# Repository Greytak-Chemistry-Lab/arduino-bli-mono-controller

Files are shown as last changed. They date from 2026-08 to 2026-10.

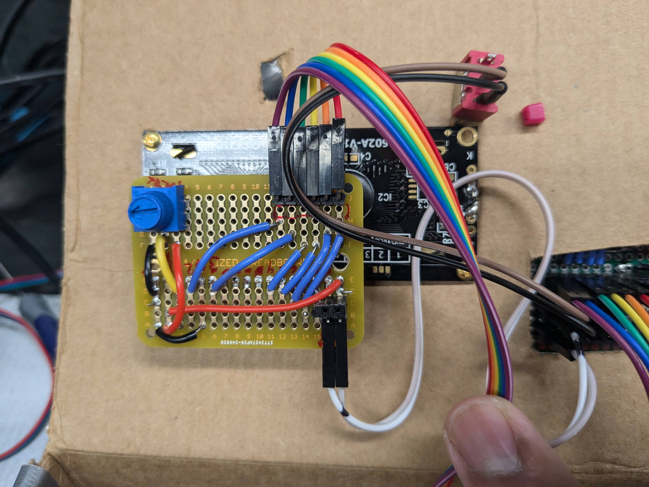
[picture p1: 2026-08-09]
og/layouts/lcd_and_button_panel/soldered lcd mini breadboard back side.jpg

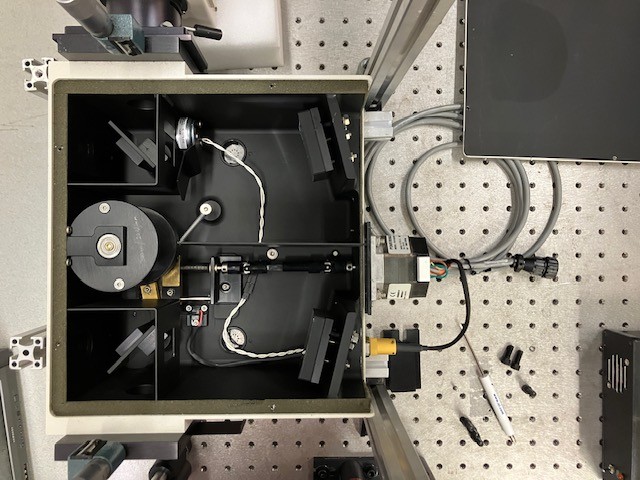
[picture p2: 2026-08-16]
og/layouts/spectrometer hardware/OBB setup with NEMA23 Kollmorgen P21NRXS-LNN-NS-17 motor and shutter.jpg

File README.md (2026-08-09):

# arduino monochromator controller
This repository is for an Arduino-based automation controller for an Optical Building Blocks (OBB) monochromator in the Greytak lab at the University of South Carolina. This monochromator was originally a manually-operated model and has been enhanced with a NEMA-17 bipolar stepper motor, driven by a DRV8825 stepper motor controller mounted on an Arduino shield. A toggle switch for mode, and a single limit switch, complete the electronic design. 

This project is an implementation of the "Arduino Basic Laboratory Instrument" described in our `arduino-bli` repository, and uses an Arduino Uno R3 microcontroller with peripheral button/LED and 16x2 LCD display boards.

Developed by the Greytak lab at the University of South Carolina. Copyright Andrew B. Greytak 2026.

For more information about our laboratory see the Greytak Chemisty Lab's [GitHub Pages site](https://greytak-chemistry-lab.github.io), or our group website.

## Purpose and overview of project

These notes are incomplete and should be improved over time.

Configuration information:
- Some instrument-specific parameters including micro-stepping configuration for the stepper motor drives (i.e., whether it will simulate a larger number of steps per revolution), steps-to-wavelength calibration, and home position are specified in the Arduino sketch.
- On startup, the program will ask if homing is necessary (it will be if the instrument was powered off in position other than home).

After startup, the program operates in two modes, selected by the mode toggle switch.
- In **manual** mode, the user can specify a desired target wavelength and a speed. The stepper motor will then move the grating to the desired position.
- In **auto** mode, the user will specify parameters for the starting wavelength, ending wavelength, speed, and number of replicates for a desired wavelength scan.
	- After setting these parameters, `Start/Next` will begin the scan. `Start/Next` normally uses a pushbutton input, but could be triggered by an active-low external signal. The LED is activated at the start of each sweep, and could be used to trigger an external recording device.
	- Pressing `Stop/Reset` will pause the scan. Holding it down will enable reset. See program comments for more info on error handling, for which this project is a good example.
	- At the conclusion of the desired replicates, the program will await the next `Start/Next` signal to repeat. Toggling to manual mode can enable re-entry of auto scan parameters.

## Repository organization (replicated in each variation-version):

- **`layouts`**: folder with description of hardware
    - Should include parts list(s) and diagrams
	- Could have subfolders for different sub-assemblies, or for minor variations in design or accessories
- **`programs`**: Software
	- Can have subfolders for different programs that can run on the same hardware
	- Remember that Arduino sketches need to live in a subfolder where the folder name and `.ino` file name are the same
- **`calibration results`**: Instrument specific data
	- used to select parameters needed for programs

## Our approach to git repositories: variations and versions

The current Greytak lab approach is that projects may proceed through "variations" and "versions". These will refer to subfolders that each include a replicate of the entire project as described above. A user will only be using a single variation/version at a time. All variations and versions will live in the same ("main") branch of the git repo. This simplifies administration by not requiring all lab members to understand the details of git branching/merging/pull requests etc. The maintainer of the repo may still choose to use branches on a short-term basis for some kind of experiment or bug fix. **Our use of these is a bit different for hardware vs code-only projects.**

Each repo will have one or more maintainers who are able to commit changes. The number of maintainers will be small -- usually Greytak and one student -- for continuity of style within the project. Other fixes or additions can be made by first demoing it in your own clone, and then asking the maintainer to copy it into the shared project.

"Variations" will refer to some major stage of development or intended features for a project. For hardware projects, this usually means different core hardware, not different software or peripherals that can be used with the same core device (those can just be added as subfolders in `layouts` or `programs`). If you do want to make some significant changes that may break compatibility with older hardware, it might be time to make a new "variation". Variations will have a name to identify them -- but this can be a codename and need not specify what the variation is for, since that could be hard to describe and could evolve over time. For most projects, we will start with a special "variation": `og` (original / original gangster), representing the project as it was when it was set up (copied over from our Subversion repos, usually). We may also have a variation representing the latest stage of development of the project. If you are about to add a major new capability, or some big algorithm or data storage change that could affect compatibility, you will want to copy the latest variation to a new "variation" folder. You may later decide to copy successful developments back into the previous variation, but your new variation could also remove features and go in a different direction. Be sure to talk to the maintainer and your lab-mates. For some repos, "current" may exist as a variation, with previous variations (if any other than "og") carved off later.

"Versions" will refer to incremental development of a variation. Versions have a number. We will use them like "tags" in Subversion. Typically, the "current" version is just the folder with the variation name only. When we are about to implement an incremental change that could affect compatibility, or if we need to capture the project just as it was at the time of some publication, **and for any situation where a program is to be used on laboratory hardware**, we will copy the "current" variation folder to a folder with the same name, but with the version number appended. Version numbers will typically be 0.1, 0.2 etc until the variation is reasonably useful, and then 1.0, 1.1 etc. Bug fixes and improved commenting can be applied (manually) to numbered "versions", but no changes should be made in them that will break compatibility. Usually, it will be preferable to do such things in the current version, rather than in a previous numbered one. **Please note that, after you copy the project into a numbered version folder and before you load it onto your hardware device**, you should change software in that folder to display the software version number on the device on startup, where that is possible.

Folders will be named (within the repo) as: "variation-version" or just "variation" for the current version of each variation.

Presently, only the `og` variation exists for this `arduino-bli-mono-controller` project, and it is designed to operate the mono with an infrared grating. Calibration information in the `og` variation folders applies to this implementation.

## Attribution and license:
> This is a project of the Greytak Chemistry Lab – `github.com/greytak-chemistry-lab/arduino-bli-mono-controller`
>
> Copyright Andrew B Greytak with applicable rights reserved by the University of South Carolina. Email: `greytak@sc.edu`.
> - Code shared via GNU Public License (GPL v3)
> - Layouts / Resources shared via CC-BY-SA-4.0
>
> See LICENSE file for details

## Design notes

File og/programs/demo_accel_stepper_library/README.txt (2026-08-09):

I used Accel Stepper library functions to control speed, acceleration, direction etc. The only issue is the motor and driver become hot quickly.

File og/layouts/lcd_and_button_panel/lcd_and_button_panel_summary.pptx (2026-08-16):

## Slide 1

Hardware layout for modular Arduino lab instrument, Greytak lab

Adapted for stepper motor-based monochromator controller project: arduino-bli-mono-controller

Digital pins 2-7: LCD output
Analog inputs A0-A5 (pins 15-19): Inputs
A0-A3: pushbuttons
A5: toggle switch (mode switch)
A4: available (used for limit switch)
Pin 13: LED/TTL output
Pins 8-12: available (used for stepper motor control)
Pins 0-1: unused

Idea is:
- power, input “bus”, and LED out goes to button panel
- LCD panel is powered from button panel
- Additional inputs can be connected to the input “bus” via peripheral connections to the button panel
- The “mode” toggle switch is one such peripheral input
- All digital inputs are active low, configured as INPUT_PULLUP (supposed to be 20k-50k internal pull-ups to 5V)

Schematic view: Fritzing

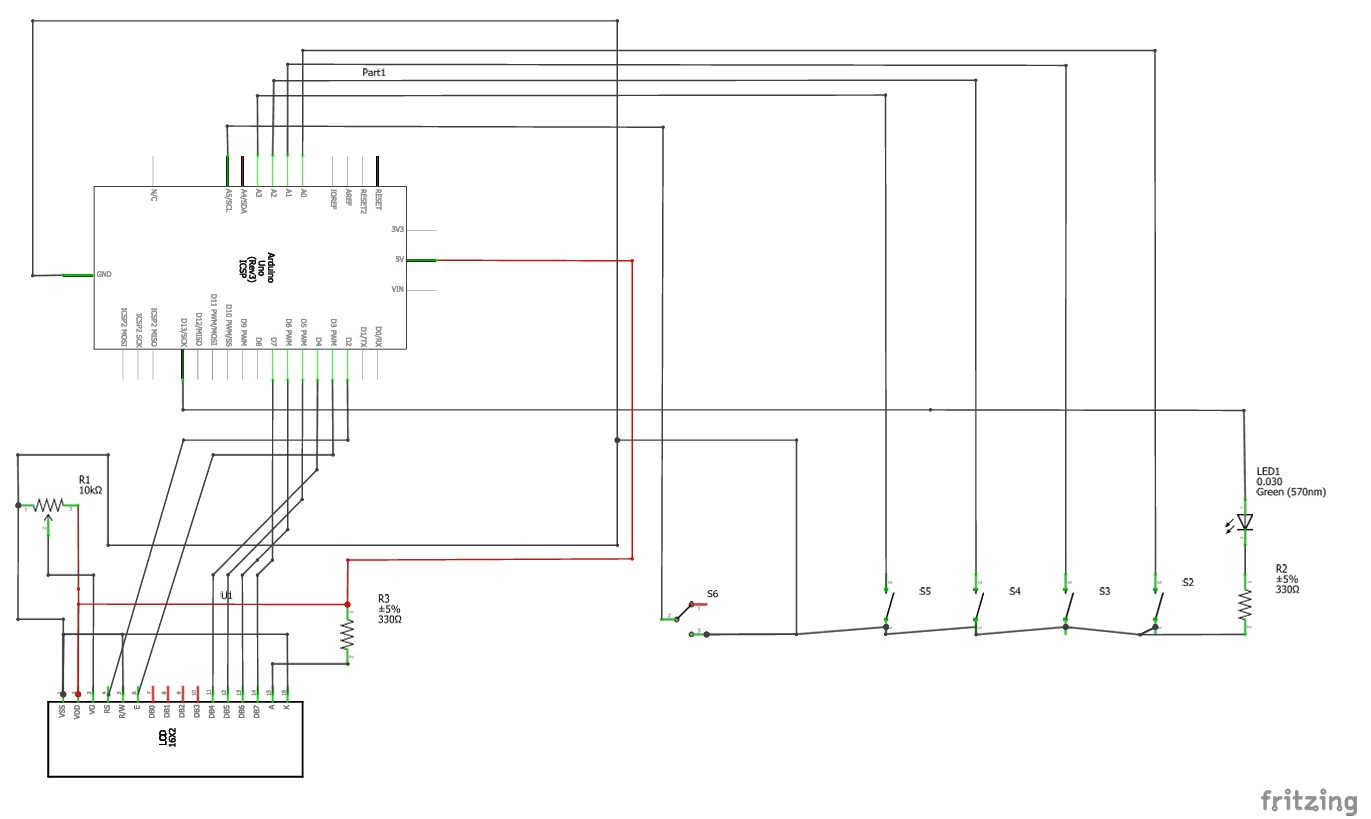
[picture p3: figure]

Copyright 2026 Andrew B. Greytak, University of South Carolina – Documentation shared via CC-BY-SA-4.0
https://github.com/Greytak-Chemistry-Lab/arduino-bli-mono-controller/LICENSE

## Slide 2

Hardware layout for modular Arduino lab instrument, Greytak lab

Digital pins 2-7: LCD output
Analog inputs A0-A5 (pins 15-19): Inputs
A0-A3: pushbuttons
A5: toggle switch (mode switch)
A4: available (used for limit switch)
Pin 13: LED/TTL output
Pins 8-12: available (used for stepper motor control)
Pins 0-1: unused

Idea is:
- power, input “bus”, and LED out goes to button panel
- LCD panel is powered from button panel
- Additional inputs can be connected to the input “bus” via peripheral connections to the button panel
- The “mode” toggle switch is one such peripheral input
- All digital inputs are active low, configured as INPUT_PULLUP (supposed to be 20k-50k internal pull-ups to 5V)

Breadboard implementation: Fritzing

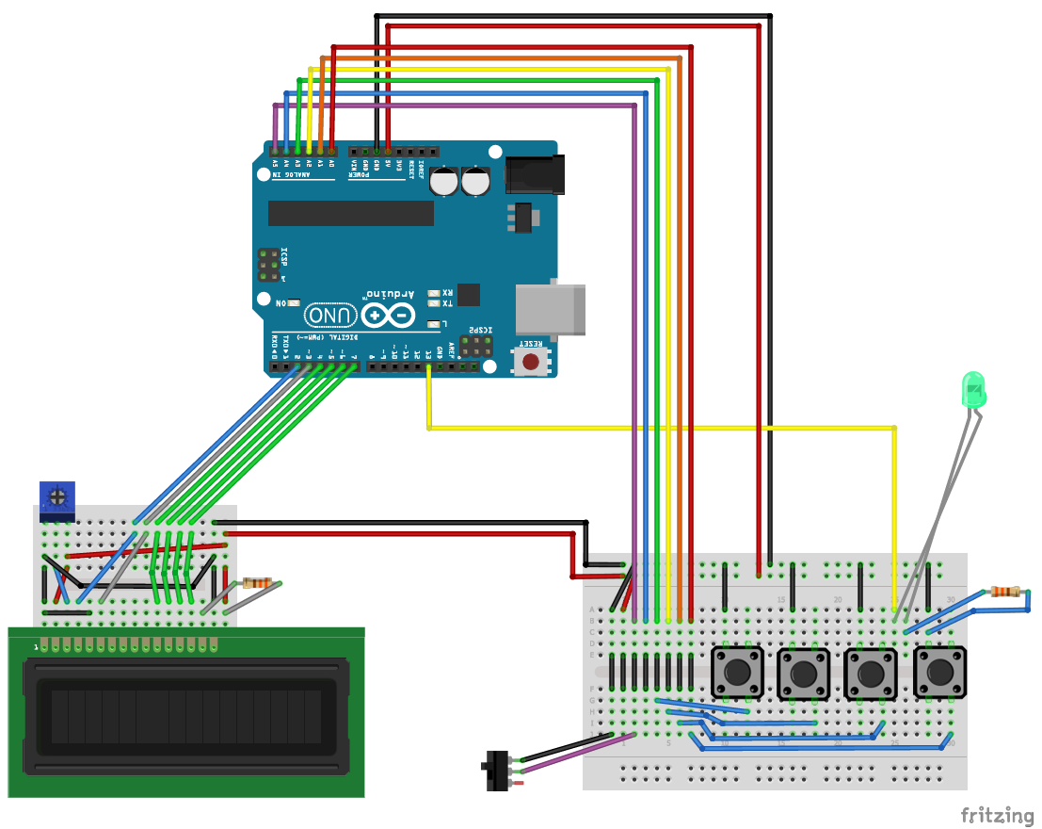
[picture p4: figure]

Copyright 2026 Andrew B. Greytak, University of South Carolina – Documentation shared via CC-BY-SA-4.0
https://github.com/Greytak-Chemistry-Lab/arduino-bli-mono-controller/LICENSE

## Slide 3

Hardware layout for modular Arduino lab instrument, Greytak lab

Soldered implementation of LCD panel:
(rendered in Fritzing, but it doesn’t understand two-sided perf boards, so we manually include views from front and back: some components are shown on both sides to illustrate where they are located. Fritzing also does not render right-angle headers. The LCD panel has right-angle male headers for signal connection, so it can be plugged directly into the Arduino if desired for testing, and can use RA male and/or standing female headers for power)

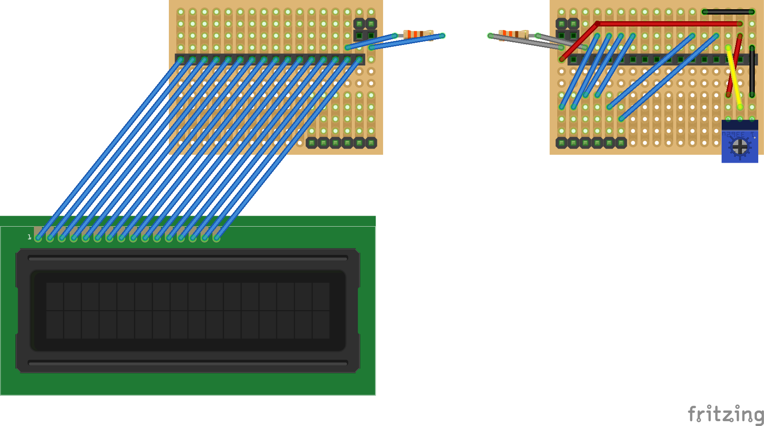
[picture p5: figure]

Digital pins 2-7: LCD output
Analog inputs A0-A5 (pins 15-19): Inputs
A0-A3: pushbuttons
A5: toggle switch (mode switch)
A4: available (used for limit switch)
Pin 13: LED/TTL output
Pins 8-12: available (used for stepper motor control)
Pins 0-1: unused

Idea is:
- power, input “bus”, and LED out goes to button panel
- LCD panel is powered from button panel
- Additional inputs can be connected to the input “bus” via peripheral connections to the button panel
- The “mode” toggle switch is one such peripheral input
- All digital inputs are active low, configured as INPUT_PULLUP (supposed to be 20k-50k internal pull-ups to 5V)

Front

Back

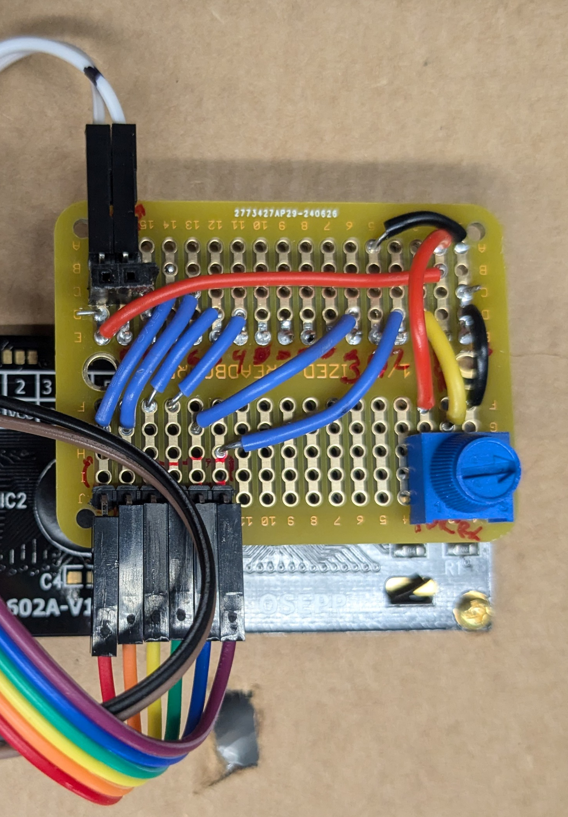
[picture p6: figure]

Copyright 2026 Andrew B. Greytak, University of South Carolina – Documentation shared via CC-BY-SA-4.0
https://github.com/Greytak-Chemistry-Lab/arduino-bli-mono-controller/LICENSE

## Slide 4

Hardware layout for modular Arduino lab instrument, Greytak lab

Soldered implementation of button panel (compact, used in NIR controller):
This arrangement was fairly difficult to solder and does not include an output header for the LED, which would be desirable if we want to be able to use that for external monitoring without splitting the wire from the Arduino to the button panel

Front (with buttons and LED)

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

Back (with headers)

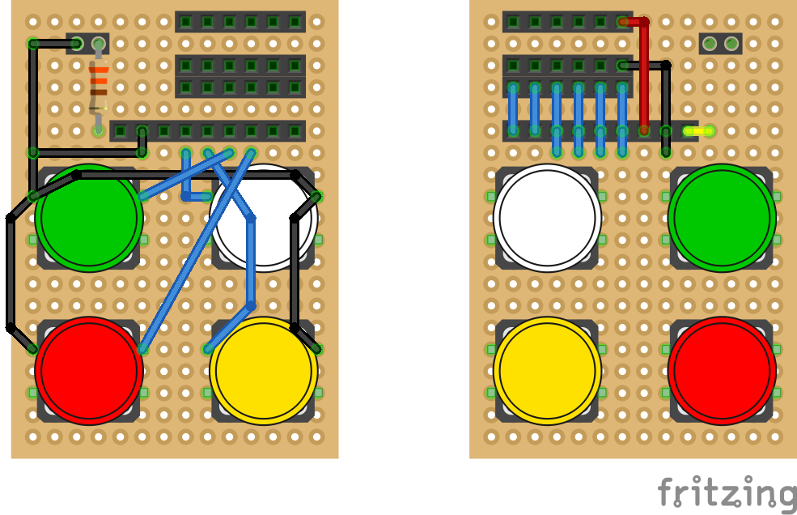
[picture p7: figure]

GND

5V

+

220 ohm resistor for LED

LED G 5V A0 A1 A2 A3 A4 A5

Perif.

Ard.

A5 A4 A3 A2 A1 A0 5V G LED

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

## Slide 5

Hardware layout for modular Arduino lab instrument, Greytak lab

Soldered implementation of button panel
(half-breadboard size):

Front (with buttons and LED)

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

Back (with headers: male headers are right-angle)

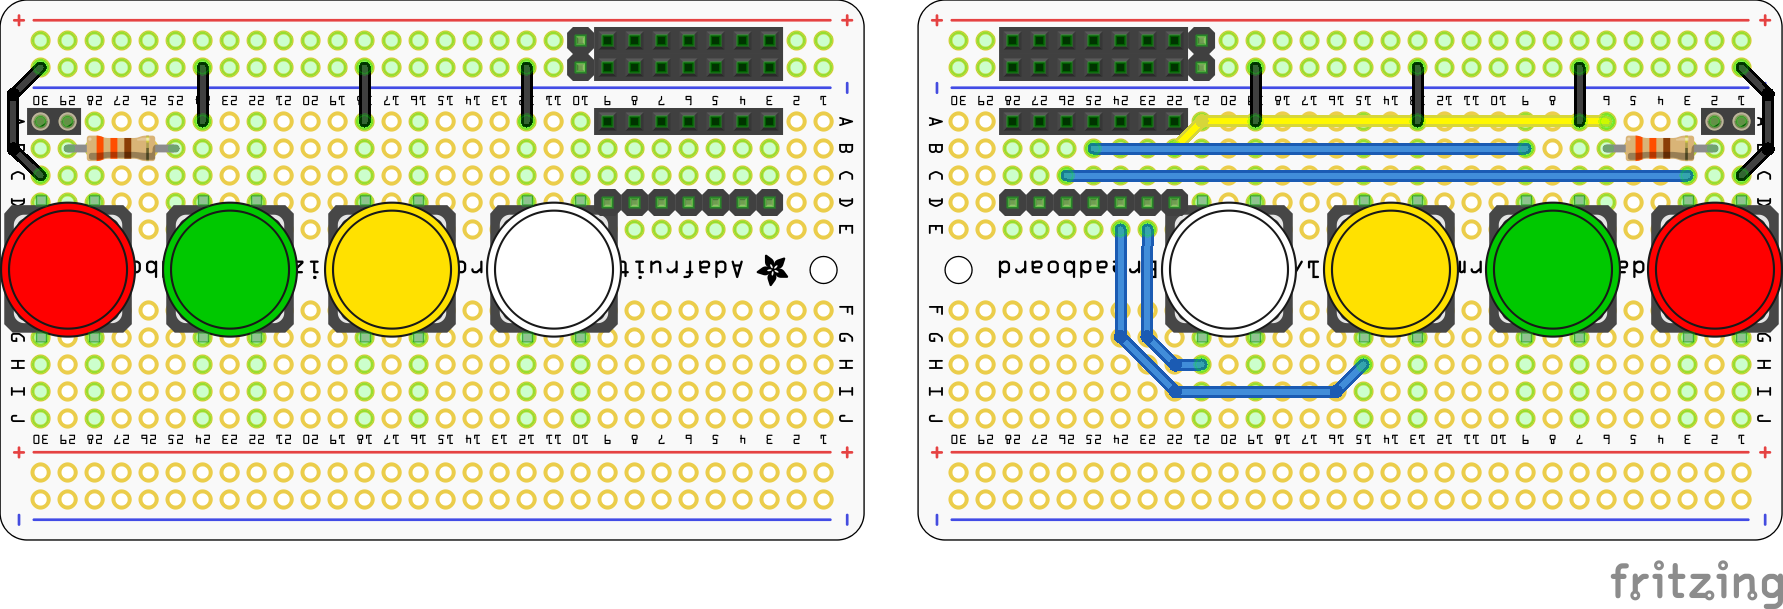
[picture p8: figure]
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

GND

5V

LED

+

LED A0 A1 A2 A3 A4 A5

Perif.

Ard.

A5 A4 A3 A2 A1 A0 LED

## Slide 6

Hardware layout for modular Arduino lab instrument, Greytak lab

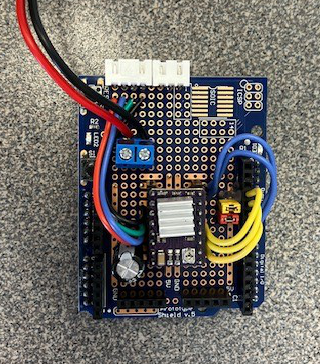
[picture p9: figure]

Motor driver shield
(prototype, similar to the one installed)

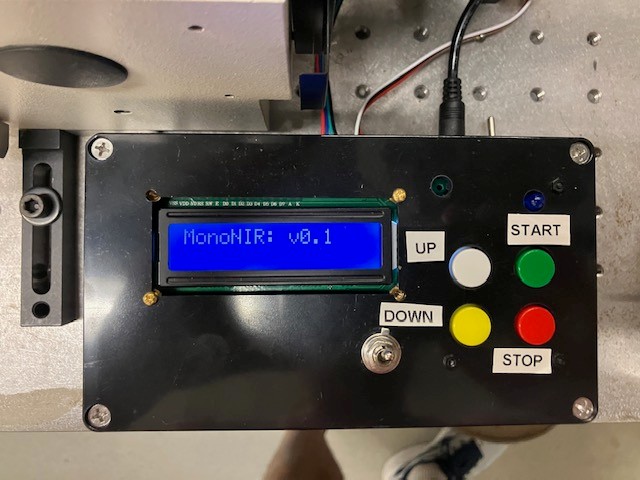
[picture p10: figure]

LED

Manual / Auto toggle switch

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

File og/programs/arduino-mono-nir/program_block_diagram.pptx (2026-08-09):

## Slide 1

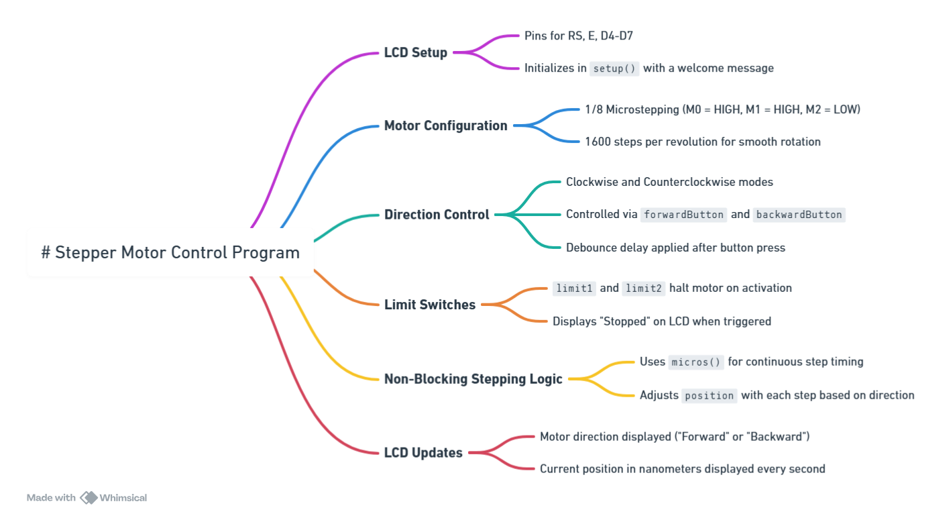
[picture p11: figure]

We should define directions in wavelength = LONGER or SHORTER and then use #define to specify which of these is clockwise or counterclockwise for motor rotation.

We can debounce by polling switches with a 100-200 ms “HOLDOFF” delay

All motor motions will be a loop in which only as many steps as can be done in HOLDOFF are carried out before checking switch input values.

We will mainly keep track of progress with position variable as integer number of nm. A subroutine will calculate the change in Steps necessary for every move of nm, and LCD will be updated each move loop iteration.

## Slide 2

Power on; possible separate power switch for motor/driver output to enable it to be shut off / cooled without resetting Arduino

setup()

Setup pins, LCD
Set motor speed

Subroutines:

loop()

if initialize (home) flag is set (first run, or commanded):

Ask user if we should initialize; possibly other config options
If commanded, initialize: run backward until limit switch, then forward slow to disengage limit switch, then define position and run forward to starting position target; un-set initialize flag

position_target loop: user selects position target; startnext or autoManual to break out
check flags
if new position was selected, move until correct position
check flags

Get start, end, speed, number of scans; break on automanual
Check flags

If not at starting position, Move backwards to start, including backlash corr. Check flags. Display ready.

Wait on start key, break on stopreset or autoManual

Check flags

positionSteps()

Returns the number of steps from home to reach a desired wavelength position in nm, based on lookup table or calibration function

if autoManual true, manual mode

if automanual false, auto mode

1. auto run setup: Display and update settings

2. auto run: Main Loop

Possible Subroutines:

moveSteps()

Move a number of steps forward or backward at the desired speed while polling limit1, limit2/stopreset

do while # scans is not completed:
Blink LED / TTL out
Move forwards to end
Check flags
Return to starting position, with backlash corr.
Display scan complete

3. auto run: Scan loop

resetPress()

A possible subroutine to start a counter when reset is pressed and check if it is held down a long time, prompting initialize flag to be set

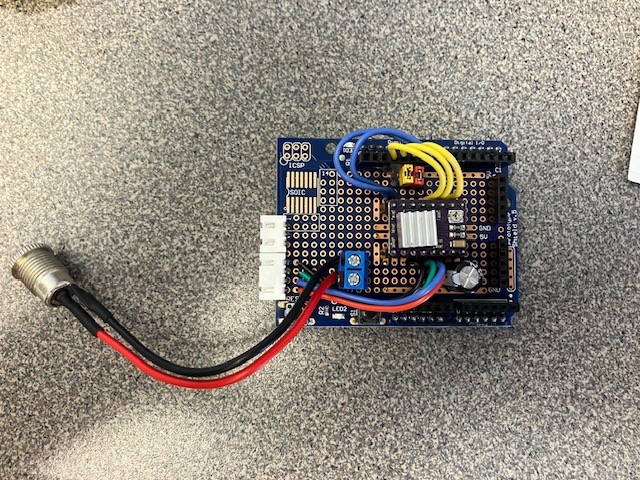
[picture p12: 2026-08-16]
og/layouts/motor_shield/photo of DRV8825 on protoshield with JST peripheral sockets and power in.jpg

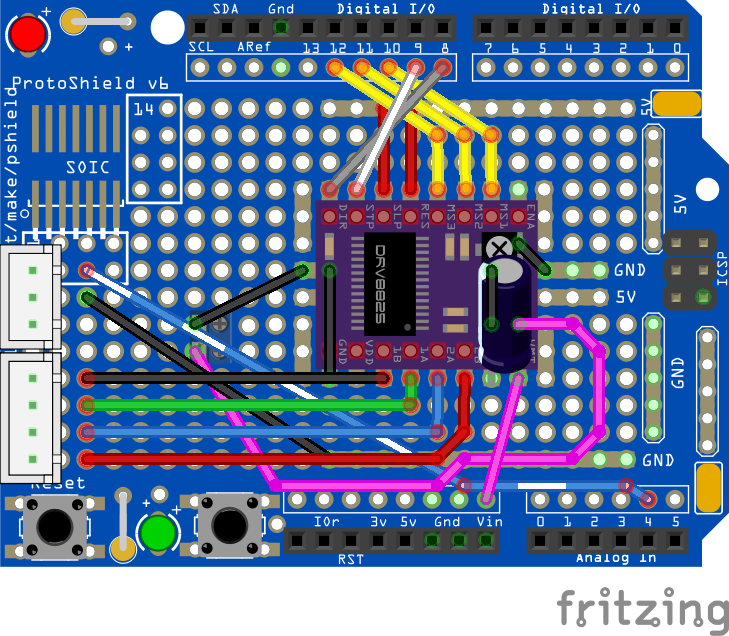
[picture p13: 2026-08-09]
og/layouts/motor_shield/fritzing/monochromator stepper motor shield_bb.png

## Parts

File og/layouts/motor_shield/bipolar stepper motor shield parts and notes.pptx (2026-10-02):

## Arduino “BLI” DRV8825 biopolar stepper motor driver shield

Uses Arduino Protoshield (v6 shown in Fritzing drawing)

Tested with a NEMA 17 bipolar stepper motor (1.5A max current) and 8:1 microstepping. Board should support up to 2A with adequate cooling.

NEMA-17 bipolar stepper
wiring: but Reddit says “there is no standard configuration for stepper motor terminals”

Adjust this screw pot while measuring the voltage on the screw head until #volts = half the #amps for desired current limit (0.75V for 1.5A)

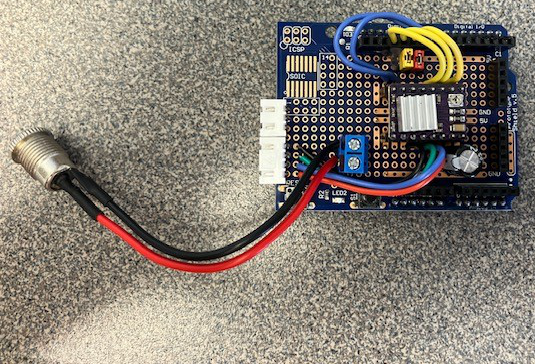
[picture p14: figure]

SLP (sleep) and RES (reset) are pulled high with jumpers in this prototype but can be soldered to 5V as indicated in the drawing.

Copyright 2026 Andrew B. Greytak, University of South Carolina – Documentation shared via CC-BY-SA-4.0
https://github.com/Greytak-Chemistry-Lab/arduino-bli-mono-controller/LICENSE


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
Control signals:
DIR: Arduino pin 8
STP (step): Arduino pin 9
MS1: Arduino pin 10 (microstepping bits)
MS2: Arduino pin 11
MS3: Arduino pin 12

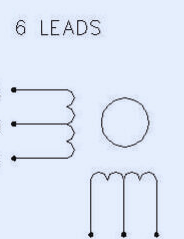
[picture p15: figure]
NEMA17 Wiring Overview
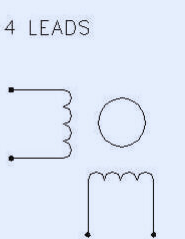
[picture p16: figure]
NEMA17 Wiring Overview

Limit switch
jack

Motor terminals

1A
2A
1B
2B

1

Motor jack

## Parts list

Part | Part Number / Supplier | Note
DRV8825 stepper motor breakout | Stepper Motor Driver Module for 3D Printer Stepper Driver 4-Layer PCB Board (Amazon/”EC Buying”, purchased as 5 pack w/ heatsinks
Limit switch (3-pin end stop switch) | WELWIK (Amazon)
Limit switch cable (1M XH2.54 3PIN Cable Endstop Switch Wire) | GRGRG (Amazon) | XH2.54 male/male
Stepper motor cable 4pin to 6pin, 1.5 M | TIEXYE (Amazon) (Compatible with NEMA 17 for Ender 3 printer) | XH2.54 mm 4pin male / PH 2.0 6pin male
100 microfarad electrolytic capacitor
JST XH2.5 2.54mm pitch socket plug adapter, 3 pin | From Amazon JST XH2.5 DIP header variety pack | Pin 1 on left when looking into plug. NO(A4)/GND/NC
JST XH2.5 2.54mm pitch socket plug adapter, 4 pin | From Amazon JST XH2.5 DIP header variety pack | Pin 1 on left when looking into plug. 1B/1A/2A/2B
2-pin screw terminal block for power input (tested with 12V) | Amazon | 9V min for DRV8825, 12V max for Arduino
22 AWG solid core wire | | On board

Documentation Copyright 2026 Andrew B. Greytak, University of South Carolina – Documentation shared via CC-BY-SA-4.0
https://github.com/Greytak-Chemistry-Lab/arduino-bli-mono-controller/LICENSE

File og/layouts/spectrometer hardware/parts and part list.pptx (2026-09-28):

## Arduino “BLI” monochromator controller – peripheral hardware setup for OBB

Repurposed Optical Building Blocks (OBB) monochromators (table is 1” grid)

A professionally-built setup with NEMA-23 stepper motor. Includes shutter solenoid (H-1079-032 1208, probably 12V) and optical limit switch.
Motor part number: Kollmorgen P21NRXS-LNN-NS-17

Our home-modified setup with NEMA-17 1.5Amp stepper motor (Twotrees).
Employs mechanical limit switch (WELWIK 3-pin end stop switch for 3D printers).

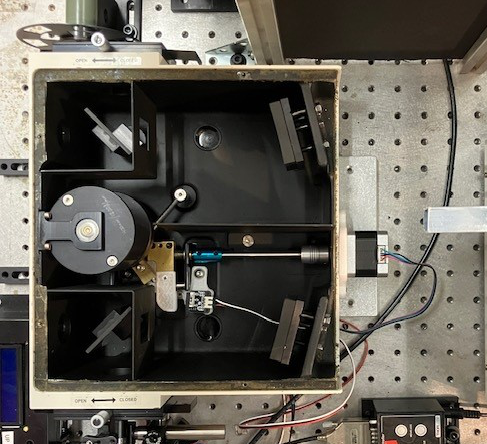
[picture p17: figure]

Copyright 2026 Andrew B. Greytak, University of South Carolina – Documentation shared via CC-BY-SA-4.0
https://github.com/Greytak-Chemistry-Lab/arduino-bli-mono-controller/LICENSE

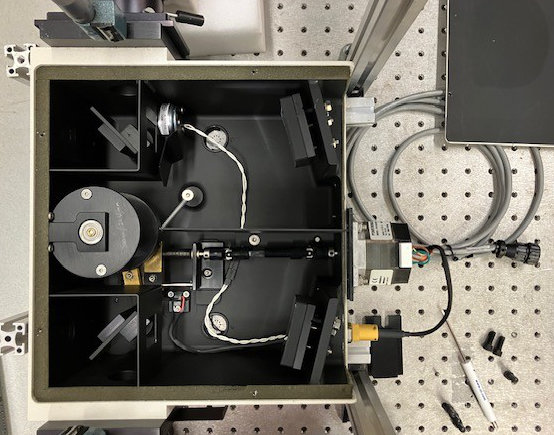
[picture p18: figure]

reducing flexible shaft coupler
6.35 mm (1/4 inch) to 5 mm

3D printed adapter for motor mount

3D printed adapters for paddle and switch mount

## Parts list

Part | Part Number / Supplier | Note
Stepper motor NEMA-17 1.5 amp | 17HS4401 / Twotrees (Amazon) | No longer available from this vendor, but part# is standard
Limit switch (3-pin end stop switch) | WELWIK (Amazon)
Limit switch cable (1M XH2.54 3PIN Cable Endstop Switch Wire) | GRGRG (Amazon) | XH2.54 male/male
Stepper motor cable 4pin to 6pin, 1.5 M | TIEXYE (Amazon) (Compatible with NEMA 17 for Ender 3 printer) | XH2.54 mm 4pin male / PH 2.0 6pin male
6.35mm (1/4”) shaft coupler | Twidec 6.35 mm rigid coupler | Blue aluminum part in photo
Flexible reducing coupler | Xnrtop 5mm to 6.35 mm aluminum
Limit switch paddle | Gryphon Drake designs “IR spectrometer limit switch” assembly (Accessible on Greytak Chemistry Lab Onshape space) | Attaches to moving part
Limit switch mount | Gryphon Drake designs “IR spectrometer limit switch” assembly | Bolts to instrument floor
Motor mount | GDD “spectrometer motor bracket”
Grating 50x50x6 mm | Newport 33010FL01-520R | For NIR: 600 lines/mm blazed 1.02 um, blaze angle 17.46 degrees

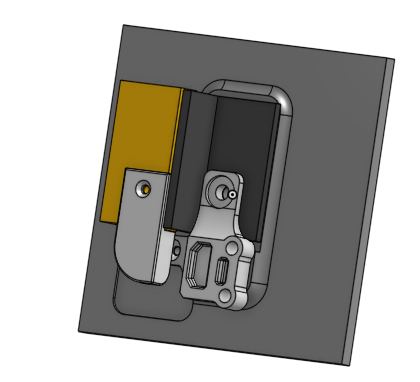
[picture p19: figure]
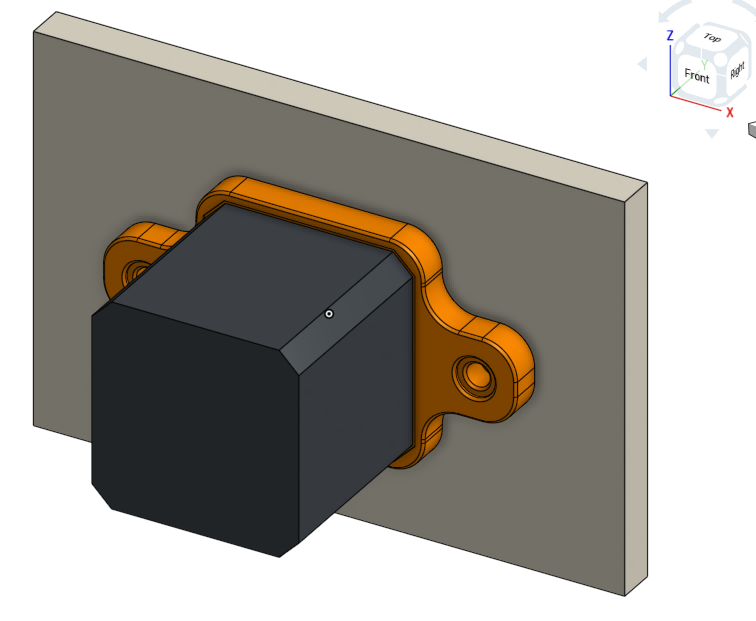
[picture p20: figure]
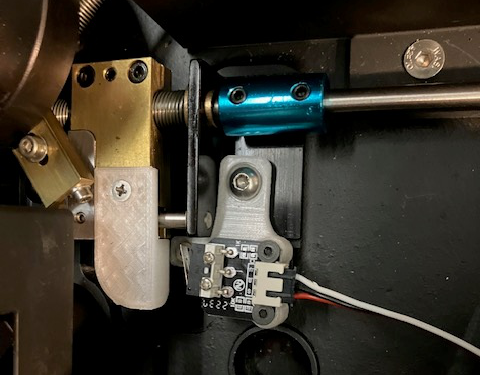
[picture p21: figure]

3D designs copyright 2024 Gryphon A. Drake
Documentation Copyright 2026 Andrew B. Greytak, University of South Carolina – Documentation shared via CC-BY-SA-4.0
https://github.com/Greytak-Chemistry-Lab/arduino-bli-mono-controller/LICENSE

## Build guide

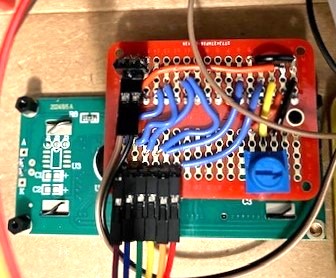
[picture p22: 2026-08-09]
og/layouts/lcd_and_button_panel/soldered lcd mini breadboard back side improved.jpg

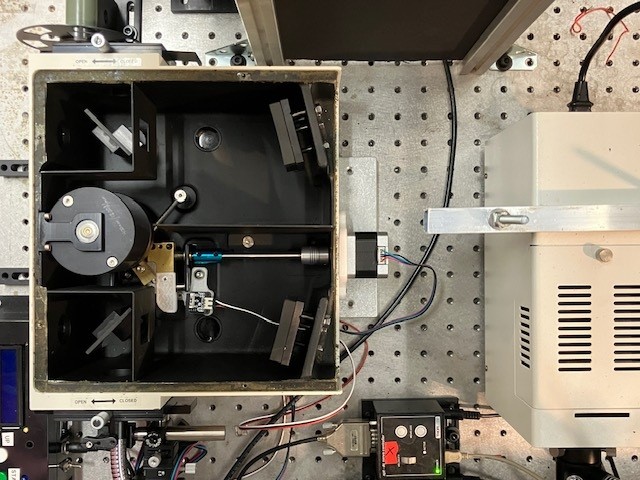
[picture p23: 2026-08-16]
og/layouts/spectrometer hardware/custom setup with NEMA17 motor.jpg

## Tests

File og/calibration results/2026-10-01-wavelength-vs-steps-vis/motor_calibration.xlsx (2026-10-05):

 | Steps | Wavelength | Steps_diff | Wavelength diff
initial tests | 5328 | 774.5 | 0 | 0
 | 9008 | 545 | 3680 | -229.5
 | 11568 | 384.5 | 6240 | -390
calc'd | 8982.4 | 546.1
set as home | 8984 | 546
 | 10747.2 | 435.8
 | 11880 | 365
 | 13880 | 240
set as steps_Max | 14000

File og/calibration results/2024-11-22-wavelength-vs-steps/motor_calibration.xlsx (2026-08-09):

Steps | Wavelength | Steps_diff | Wavelength diff
1328 | 1990 | 0 | 0
1968 | 1910 | 640 | -80
2608 | 1830 | 1280 | -160
3248 | 1750 | 1920 | -240
3888 | 1670 | 2560 | -320
4528 | 1590 | 3200 | -400
5168 | 1510 | 3840 | -480
5808 | 1430 | 4480 | -560
6448 | 1350 | 5120 | -640
7088 | 1270 | 5760 | -720
7728 | 1190 | 6400 | -800
8368 | 1110 | 7040 | -880
9008 | 1030 | 7680 | -960
9648 | 950 | 8320 | -1040
10288 | 870 | 8960 | -1120
10928 | 790 | 9600 | -1200
11168 | 760 | 9840 | -1230

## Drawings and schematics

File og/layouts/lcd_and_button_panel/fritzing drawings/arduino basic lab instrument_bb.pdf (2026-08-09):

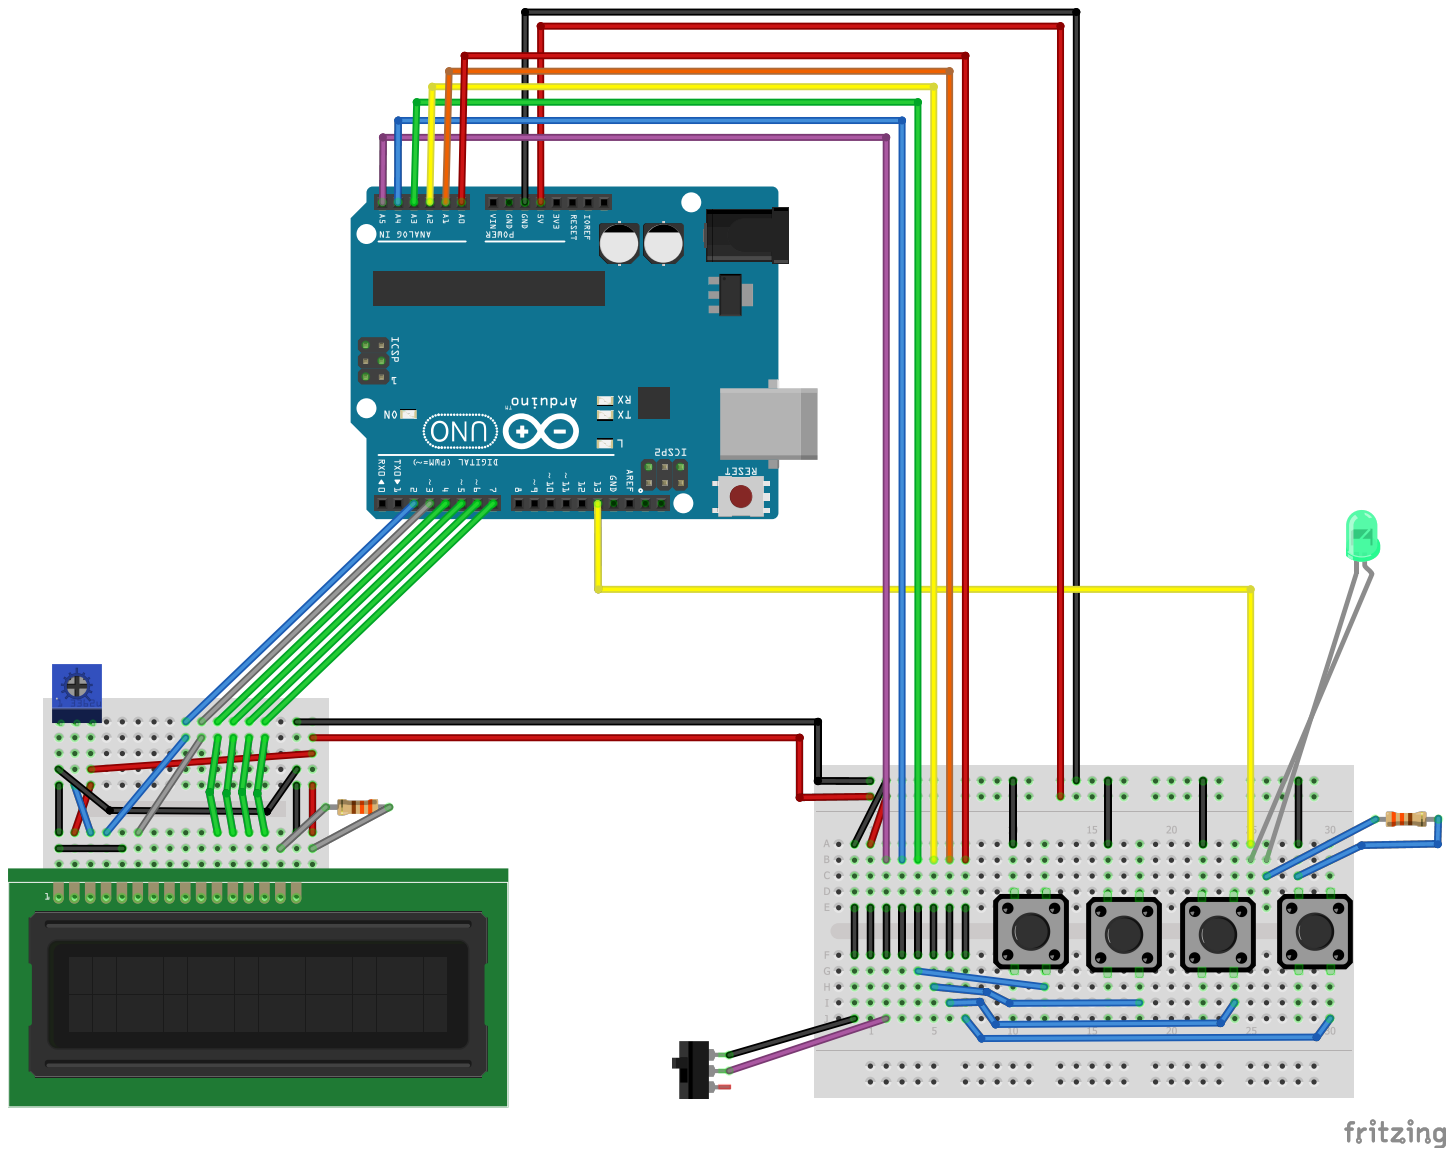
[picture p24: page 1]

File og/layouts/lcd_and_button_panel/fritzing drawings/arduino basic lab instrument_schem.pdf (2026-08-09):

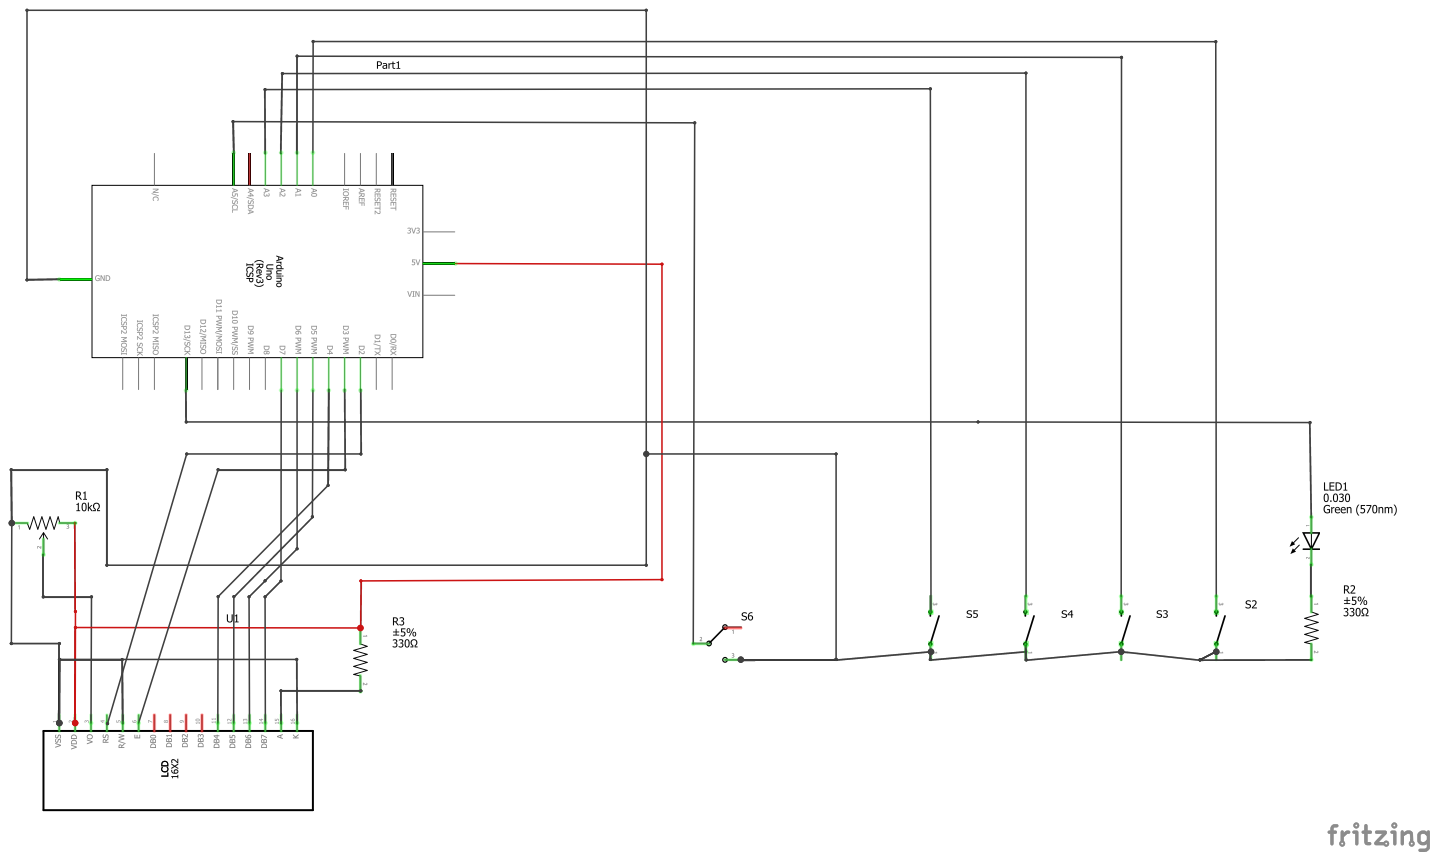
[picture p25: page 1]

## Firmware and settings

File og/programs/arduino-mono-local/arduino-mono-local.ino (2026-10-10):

// Stepper motor control for visible OBB monochromator, including manual positioning and 
// automated scanning.
// This sketch builds on a "basic lab instrument" design with standardized LCD and
// pushbutton interfaces. The physical layout additionally includes a custom motor
// shield incorporating a DRV8825 bipolar stepper motor driver and limit switch connection,
// and a manual toggle switch to change between manual mode (switch closed) and 
// auto mode (switch open). 
// It should additionally be possible to trigger automatic scans via an external, active-low
// signal to startnextButtonPin, and to monitor automatic scan starts via a rising-edge TTL 
// signal on the ledPin.
// Timing is via delayMicroseconds() calls. Future developments could enable more precise
// or flexible control via elapsed time. 
// The range of accessible speeds can be adjusted via  microstepping settings for the DRV8825,
// and different monochromators could be accommodated via wavelength calibrations.
// The code enables replicate scans in auto mode.
// We believe the error handling here is a good example for other projects.
// Enables rapid scrolling of the target position when UP or DOWN is held down.
// Homing on startup is currently optional, but is strongly advised for actual use because 
// position limits are not monitored in hardware after the initial homing step.
// Made by Abdulla Shaker and Andrew Greytak. Update this repo for latest information.

// Attribution: Greytak Chemistry Laboratory - University of South Carolina.
// Copyright Andrew B Greytak 2026 with applicable rights reserved by USC:
// github.com/greytak-chemistry-lab/arduino-bli-mono-controller
//
// See arduino-bli-mono-controller/LICENSE file for license info
// variation/version = og  (current/development version)

#include <LiquidCrystal.h>
#include "settings.h"

// Define pin numbers for LCD display
const int lcdRSPin = 2;
const int lcdEPin = 3;
const int lcdD4Pin = 4;
const int lcdD5Pin = 5;
const int lcdD6Pin = 6;
const int lcdD7Pin = 7;

// Define input pin numbers
const int upButtonPin = 14;
const int downButtonPin = 15;
const int startnextButtonPin = 16;
const int stopresetButtonPin = 17;
const int limit1Pin = 18;
const int manualModePin = 19;  // LOW (switch closed) = auto

const int HOLDOFF = 150;     // milliseconds after button press before we read again
const int INITDELAY = 2000;  // delay on setup()
const int STARTDELAY = 500;  // delay after next before accepting start signal
const int CYCLEDELAY = 50;   // for polling button presses and limit switches while moving

// Define LED pin
const int ledPin = LED_BUILTIN;

// Motor control and microstepping pins
const int dirPin = 8;
const int stepPin = 9;
//  microstepping pins 
const int M0 = 10;
const int M1 = 11;
const int M2 = 12;

// Motor settings
const long stepsPerRevolution = 1600;  // 1/8 microstepping
// Each step takes at least 2*stepInterval microseconds
const long backlashSteps = 10;
const long steps_Min = backlashSteps;
const long steps_Max = long(8.75 * stepsPerRevolution);  // SET APPROPRIATELY TO AVOID CRASH

// Direction definitions
// With our setup, CLOCKWISE moves FORWARD (away from limit1 switch)
// COUNTERCLOCKWISE moves BACKWARD (toward limit1 switch)
// Backward moves should be followed by backlash correction
#define CLOCKWISE 1
#define COUNTERCLOCKWISE 0

// ******** ADJUST HERE FOR INSTRUMENT-SPECIFIC CALIBRATION ***************
// Do not actually adjust here: Set via macros specified in settings.h
// Polynomial constants to convert nm position to steps, from calibration
float c0 = C0;
// currently only c1 is needed: negative since increasing steps leads to shorter wavelength position
float c1 = C1;   
float c2 = C2;
float c3 = C3;

// speed selection
// stepInterval in us: ex: 1000000 / (2*nm_per_min*8/60) with c1=(-)8
unsigned long stepInterval = STEPINTERVAL;  // 4000 microseconds half-period for 125 steps per second
long speed_nm_min=0; // selected speed in nm/min
long slow_us=0;   // delay based on speed
const long speed_Min=SPEEDMIN; // minimum speed, nm/min: slower than 240 incompatible with current delay scheme
const long speed_Max=SPEEDMAX; // Speed max, nm/min, max=420 for stepInterval=4000
const long speed_incr=SPEEDINCR; // multiple of 60
long autoscan_speed=0; //initialize autoscan speed 
const int coarse_button_incr=COARSEBUTTONINCR; // multiplier for faster scrolling (manual) and setting auto endpoints

// Wavelength configuration and counters
const long steps_offset = STEPSOFFSET;   // Offset after homing
long stepCounter = 0;            // Tracks current step position from home
const long startPosition = STARTPOSITION;  // Start position in nm (green mercury line)
long position;                   // current position in nm
const long position_Max = POSITIONMAX;  // longest wavelength allowed
const long position_Min = POSITIONMIN;   // shortest wavelength allowed
const int  position_incr= POSITIONINCR; // increment for position selection button presses 
// ******** END INSTRUMENT-SPECIFIC CALIBRATION ***************



// Additional global variable initialization
long autoscan_Start,autoscan_End,autoscan_Speed,autoscan_Cycles; // need these to be global so they don't get lost switching auto/manual
bool isFirstStart = true;  // Flag to indicate we are on very first start
bool hardReset = true; // Flag to indicate that scan parameters should be set to default on setup() or next start of loop
bool isHomed = false;      // flag to indicate homing is not done yet

// Initialize LCD
LiquidCrystal lcd(lcdRSPin, lcdEPin, lcdD4Pin, lcdD5Pin, lcdD6Pin, lcdD7Pin);


// Function to calculate motor steps based on target wavelength
long positionSteps(long position_requested) {
  double prf, stepsf;
  prf = (double)(position_requested - startPosition);
  stepsf = c0 + c1 * prf + c2 * pow(prf, 2) + c3 * pow(prf, 3);
  return (long)(stepsf) + steps_offset;  // Return as long integer since motor steps are discrete
}



// Function to calculate current wavelength from step count, currently assume linear 
long stepsPosition(long currentSteps) {
  double stepsf, pf;
  stepsf = (double)(currentSteps - steps_offset);
  pf = (stepsf - c0) / c1;
  return (long)(pf) + startPosition;
}

// Function to round position_target
long positionRound(long position_requested) {
  return position_requested + ( (position_incr-1) - ((position_requested-1)%position_incr) );
}

// Function to display current position
void displayPosition() {
    lcd.setCursor(0, 1);
    position=stepsPosition(stepCounter);
    lcd.print(position);
    lcd.write("nm");
    lcd.setCursor(8, 1);
    lcd.print(stepCounter);
    lcd.write("st");
}

// Function to handle reset button presses
int resetHandler(int errorPin) {
  int resetval=1;
  long resetTime, elapsedTime;
  resetTime=millis();
  lcd.clear();
  lcd.setCursor(0,0);
  lcd.print("Fault! Pin ");
  lcd.print(errorPin);
  position=positionSteps(stepCounter);
  displayPosition();
  while(digitalRead(errorPin) == LOW) { // Button is still pressed
    delay(HOLDOFF);
  }
  delay(STARTDELAY);
  lcd.setCursor(0,0);
  lcd.print("Fault:Next/Reset");
  while(digitalRead(startnextButtonPin)==HIGH && digitalRead(stopresetButtonPin)==HIGH) {
    delay(HOLDOFF);
    if(digitalRead(startnextButtonPin)==LOW) { // clear error and continue
      resetval=0;
      break;
    }
    if(digitalRead(stopresetButtonPin)==LOW) {
      resetTime=millis();
      while(digitalRead(stopresetButtonPin)==LOW) {
        elapsedTime=millis() - resetTime;
        if(elapsedTime > INITDELAY) {
          resetval=2; // hard reset
          break;
        }
      }
      break;
    }
  }
lcd.clear();
lcd.setCursor(0,0);
lcd.print("Resetval:");
lcd.print(resetval);
delay(STARTDELAY);
lcd.clear();
return resetval;
}

// Function to apply backlash correction
void applyBacklashCorrection() {
  int i;
  lcd.setCursor(0, 1);
  lcd.print("Backlash Correct");  // Feedback to show backlash correction
  digitalWrite(dirPin, COUNTERCLOCKWISE);
  for (i = 0; i < backlashSteps; i++) {
    digitalWrite(stepPin, HIGH);
    delayMicroseconds(stepInterval);
    digitalWrite(stepPin, LOW);
    delayMicroseconds(stepInterval);
    stepCounter--;
  }
  delay(HOLDOFF);
  digitalWrite(dirPin, CLOCKWISE);
  for (i = 0; i < backlashSteps; i++) {
    digitalWrite(stepPin, HIGH);
    delayMicroseconds(stepInterval);
    digitalWrite(stepPin, LOW);
    delayMicroseconds(stepInterval);
    stepCounter++;
  }
  lcd.setCursor(0, 1);            // Clear backlash message
  lcd.print("                ");  // Clear the line
}


// Function to perform homing and set steps_offset
void homeMotor() {
  // Move reverse until limit1 switch is closed
  digitalWrite(dirPin, COUNTERCLOCKWISE);                                              // Set motor direction to backward
  while (digitalRead(limit1Pin) == HIGH && digitalRead(stopresetButtonPin) == HIGH) {  // Keep moving until limit switch is triggered
    digitalWrite(stepPin, HIGH);                                                       // Step pulse
    delayMicroseconds(stepInterval);                                                   // Control speed 
    digitalWrite(stepPin, LOW);
    delayMicroseconds(stepInterval);
  }

  // Move forward to set zero position
  digitalWrite(dirPin, CLOCKWISE);  // Set motor direction to forward
  // first, move forward to disengage limit switch
  stepCounter = 0; // temporary value until we move forward to real zero
  while (( digitalRead(limit1Pin) == LOW || stepCounter < backlashSteps) && digitalRead(stopresetButtonPin) == HIGH) {  // Keep moving until limit switch is triggered
    digitalWrite(stepPin, HIGH);                                                      // Step pulse
    delayMicroseconds(stepInterval);                                                  // Control speed
    digitalWrite(stepPin, LOW);
    delayMicroseconds(stepInterval);
    stepCounter++;
  }

  // now, move forward to startPosition
  stepCounter = 0; // this is the real zero point
  while (stepCounter < steps_offset && digitalRead(stopresetButtonPin) == HIGH) {
    digitalWrite(stepPin, HIGH);
    delayMicroseconds(stepInterval);
    digitalWrite(stepPin, LOW);
    delayMicroseconds(stepInterval);
    stepCounter++;
  }
  position = stepsPosition(stepCounter);  //ensures the motor's position is calculated dynamically based on its actual step count
  // we are now homed, and the position should be startPosition
}

void setup() {
  // set up the LCD's number of columns and rows
  lcd.begin(16, 2);
  lcd.clear();
  lcd.setCursor(0, 0);
  lcd.print(INSTRTYPE);
  lcd.setCursor(0, 1);
  lcd.print("BLI-mono: og");
  delay(INITDELAY);

  pinMode(upButtonPin, INPUT_PULLUP);
  pinMode(downButtonPin, INPUT_PULLUP);
  pinMode(startnextButtonPin, INPUT_PULLUP);
  pinMode(stopresetButtonPin, INPUT_PULLUP);
  pinMode(limit1Pin, INPUT_PULLUP);
  pinMode(manualModePin, INPUT_PULLUP);

  pinMode(dirPin, OUTPUT);
  pinMode(stepPin, OUTPUT);
  pinMode(M0, OUTPUT);
  pinMode(M1, OUTPUT);
  pinMode(M2, OUTPUT);

  pinMode(ledPin, OUTPUT);
  digitalWrite(ledPin, LOW);

  // Set microstepping to 1/8 (M0 = HIGH, M1 = HIGH, M2 = LOW)
  digitalWrite(M0, HIGH);
  digitalWrite(M1, HIGH);
  digitalWrite(M2, LOW);


  // Ask if user wants to home
  lcd.clear();
  lcd.setCursor(0, 0);
  lcd.print("Home?");
  lcd.setCursor(0, 1);
  lcd.print("Start=Y Stop=N");

  while (isFirstStart) {
    if (digitalRead(startnextButtonPin) == LOW) {  // User presses Start/Next for Yes
      delay(HOLDOFF);
      lcd.clear();
      lcd.setCursor(0, 0);
      lcd.print("Homing...");
      homeMotor();
      lcd.setCursor(0, 1);
      lcd.print("Homing Complete");
      // position = startPosition; // should be set in homeMotor()
      isFirstStart = false;
      isHomed = true;
      delay(INITDELAY);
      break;
    }
    if (digitalRead(stopresetButtonPin) == LOW) {  // User presses Stop/Reset for No
      delay(HOLDOFF);
      lcd.clear();
      lcd.setCursor(0, 0);
      lcd.print("Skipping Home");
      // some question here as to whether to set stepCounter to steps_offset, or change steps_offset to zero if we don't home
      stepCounter = steps_offset;
      position = startPosition;
      delay(INITDELAY);
      isFirstStart = false;
      break;
    }
  }



  /*lcd.setCursor(0, 1);
  lcd.print("Ready");
*/
  delay(STARTDELAY);
}

void loop() {
  // the following boolean flags are 1 if true, even if representing active-low signal
  bool upButton, downButton, startnextButton, stopresetButton, limit1, manualMode;
  long position_target, button_time;
  long steps_target;
  int cycles_completed=0, button_speed;
  int resetval=0;

  if(hardReset==true) { // First start, or user has commanded a hard reset
    autoscan_Start=startPosition;
    autoscan_End=position_Min;
    autoscan_Speed=speed_Max;
    autoscan_Cycles=1;
    speed_nm_min=0;
    hardReset=false;
  }

  manualMode=!digitalRead(manualModePin); // manualMode is true (switch closed) for manual mode
  if (manualMode == true) {  // Manual mode
    // speed selection for manual mode
    if(speed_nm_min==0) { // Manual speed has not been set, or a reset was commanded
      speed_nm_min=speed_Max;
      lcd.clear();
      lcd.setCursor(0,0);
      lcd.print("Speed: ");
      // lcd.print(" nm/min");
      while( manualMode == true && digitalRead(startnextButtonPin)==HIGH ) {
        if (digitalRead(upButtonPin)==LOW){
          speed_nm_min +=speed_incr;//increase speed
          if(speed_nm_min>speed_Max){
            speed_nm_min -=speed_incr;
          }
        }
        if (digitalRead(downButtonPin)==LOW){
          speed_nm_min-=speed_incr;
          if(speed_nm_min<speed_Min){
            speed_nm_min+=speed_incr;
          }
        }
        // display the updated speed
        lcd.setCursor(6,0);
        lcd.print(speed_nm_min);
        lcd.print(" nm/min");
        lcd.write(" ");
        delay(HOLDOFF);
        // Check for mode change
        manualMode = !digitalRead(manualModePin);
        // Check for reset
        if(digitalRead(stopresetButtonPin) == LOW) 
          resetval=resetHandler(stopresetButtonPin);
        if(resetval==2)
          goto bailout;
        if(resetval==1) 
          break;     
      } // end manual speed selection loop
    }
    else { // display current speed briefly
      lcd.clear();
      /*lcd.setCursor(0,0);
      lcd.print("Speed:");
      lcd.setCursor(6,0);
        lcd.print(speed_nm_min);
        lcd.print(" nm/min");
        lcd.write(" ");
        delay(HOLDOFF);
      delay(STARTDELAY);*/

    }

    // position selection for manual mode
    button_time=0;
    upButton=0;
    downButton=0;
    button_speed=1;

    position_target = positionRound(position) ; // Start manual mode from our current position
    lcd.clear();
    lcd.setCursor(0, 0);
    lcd.print("Manual,tgt=");
    lcd.print(position_target);
    lcd.write(' ');
    lcd.setCursor(0, 1);
    lcd.print(position);
    lcd.write("nm");
    lcd.setCursor(8, 1);
    lcd.print(stepCounter);
    lcd.write("st");

    // while loop for setting up the target position
    while( manualMode == true && digitalRead(startnextButtonPin)==HIGH ) {
      lcd.setCursor(11, 0);
      lcd.print(position_target);
      lcd.write(' ');  // Clear extra characters
      delay(HOLDOFF);

      // Adjust target wavelength with buttons
      if (digitalRead(upButtonPin) == LOW) { // up button is currently pressed
        if(upButton==0) { // just pressed button
          upButton=1;
          button_time=millis();
          button_speed=1;
        }
        if(millis() - button_time > INITDELAY) {
          button_speed=coarse_button_incr;
        }
        position_target += button_speed*position_incr;  // Increase 
        // check if this will be a problem
        if (position_target > position_Max || positionSteps(position_target) < steps_Min) {
          position_target -= button_speed*position_incr;  // if a problem, undo change
        }
      }
      else { // up button is not pressed
        upButton=0;
      }

      if (digitalRead(downButtonPin) == LOW) { // down button is currently pressed
        if(downButton==0) { // just pressed button
          downButton=1;
          button_time=millis();
          button_speed=1;
        }
        if(millis() - button_time > INITDELAY) {
          button_speed=coarse_button_incr;
        }
        position_target -= button_speed*position_incr;  // Decrease 
        // check if this will be a problem
        if (position_target < position_Min || positionSteps(position_target) > steps_Max) {
          position_target += button_speed*position_incr;  // if a problem, undo change
        }
      }
      else {
        downButton=0;
      }


      // Check for mode change
      manualMode = !digitalRead(manualModePin);
      // Check for reset
      if(digitalRead(stopresetButtonPin) == LOW) 
        resetval=resetHandler(stopresetButtonPin);
      if(resetval==2)
        goto bailout;
      if(resetval==1){
        speed_nm_min=0; // trigger speed selection on next loop
        break;
      }
    } // end manual position selection loop

    // If we are still in manual mode and position_target is different from current position:
    if (manualMode == true && position_target != position) {
      lcd.clear();
      lcd.setCursor(0, 0);
      lcd.print("Tgt:");
      lcd.print(position_target);
      lcd.print("nm ");
      steps_target = positionSteps(position_target);  // Get steps for target wavelength
      lcd.print(steps_target);
      lcd.write("st ");
      delay(HOLDOFF); // Wait so user can see the target wavelength / steps for debugging (manual mode)

      // extra delay calculation for speed selection, c1 is steps per nm from calibration
      slow_us=(long)max((1000000.0 / (((double)speed_nm_min / 60) * abs(c1))) - (2.0 * (double)stepInterval), 0); 

      // Move motor to target steps
      if (steps_target > stepCounter) {  // move forward
        digitalWrite(dirPin, CLOCKWISE);
        // ABG: Use do ... while here so we can check that stopreset hasn't been pushed
        do {
          digitalWrite(stepPin, HIGH);
          delayMicroseconds(stepInterval);
          digitalWrite(stepPin, LOW);
          delayMicroseconds(stepInterval);
          delayMicroseconds(slow_us);
          stepCounter++;
          // display current position: leaving option to not do this every step in case that makes it too slow
          if(stepCounter % 8 == 0) {
            displayPosition();
          }
          if(digitalRead(stopresetButtonPin) == LOW) 
            resetval=resetHandler(stopresetButtonPin);
          if(resetval==2)
            goto bailout;
          if(resetval==1)
            break;  
        } while (stepCounter < steps_target);
      } else if (steps_target < stepCounter) {  // move backward, will require backlash correction
        digitalWrite(dirPin, COUNTERCLOCKWISE);
        // ABG: Use do ... while here so we can check that stopreset hasn't been pushed
        do {
          digitalWrite(stepPin, HIGH);
          delayMicroseconds(stepInterval);
          digitalWrite(stepPin, LOW);
          delayMicroseconds(stepInterval);
          delayMicroseconds(slow_us);
          stepCounter--;
          // display current position: leaving option to not do this every step in case that makes it too slow
          if(stepCounter % 8 == 0) {
            displayPosition();
          }
          if(digitalRead(stopresetButtonPin) == LOW) 
            resetval=resetHandler(stopresetButtonPin);
          if(resetval==2)
            goto bailout;
          if(resetval==1)
            break;  
        } while (stepCounter > steps_target);
        applyBacklashCorrection();
      } 

      // Synchronize stepCounter and position with the new target
      // stepCounter = targetSteps; // ABG: this is updated as we move, above
      position = stepsPosition(stepCounter);
    } // end of manual movement 
  } // end of manual segment


  if (manualMode == false) {  // Auto mode: switch open

    lcd.clear();
    lcd.setCursor(0, 0);
    lcd.print("Auto mode setup");

    delay(INITDELAY);

    // set Auto Mode parameters: autoscan_Start, autoscan_End, autoscan_Speed, autoscan_Cycles 
    // set autoscan_Start
    lcd.clear();
    lcd.setCursor(0, 0);
    lcd.print("Start Pos=");
    lcd.print(autoscan_Start);
    lcd.write(' ');
    lcd.setCursor(0, 1);
    lcd.print(position);
    lcd.write("nm");
    lcd.setCursor(8, 1);
    lcd.print(stepCounter);
    lcd.write("st");
    position_target=positionRound(autoscan_Start);

    // do while loop for setting up autoscan_Start
    button_speed=coarse_button_incr;
    do {
      lcd.setCursor(10, 0);
      lcd.print(position_target);
      lcd.write(' ');  // Clear extra characters
      delay(HOLDOFF);
      // Adjust target with buttons
      if (digitalRead(upButtonPin) == LOW) {
        position_target += button_speed*position_incr;  // Increase (fast)
        // check if this will be a problem
        if (position_target > position_Max || positionSteps(position_target) < steps_Min) {
          position_target -= button_speed*position_incr;  // if a problem, undo change
        }
      }
      if (digitalRead(downButtonPin) == LOW) {
        position_target -= button_speed*position_incr;  // Decrease (fast)
        // check if this will be a problem
        if (position_target < position_Min || positionSteps(position_target) > steps_Max) {
          position_target += button_speed*position_incr;  // if a problem, undo change
        }
      }
      // Check for mode change
      manualMode = !digitalRead(manualModePin);
      if (manualMode == true) { // user switched to manual
        goto bailout;
      }
    } while (digitalRead(startnextButtonPin) == HIGH);
    autoscan_Start=position_target;
    button_speed=1;
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

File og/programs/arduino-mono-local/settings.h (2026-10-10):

// select instrument
#define VIS
//#define NIR

// ******** ADJUST HERE FOR INSTRUMENT-SPECIFIC CALIBRATION ***************
#ifdef VIS

#define INSTRTYPE "Vis-local"
// Polynomial constants to convert nm position to steps, from calibration
#define C0  0
// currently only c1 is needed: negative since increasing steps leads to shorter wavelength position
#define C1  -16  // visible: 16 steps per nm. 125 steps per second, below. So 7.8125 nm/s scanning
#define C2  0
#define C3  0

// speed selection
// stepInterval in us: ex: 1000000 / (2*nm_per_min*8/60) with c1=(-)8
#define STEPINTERVAL 4000;  // 4000 microseconds half-period for 125 steps per second
//long speed_nm_min=0; // selected speed in nm/min
//long slow_us=0;   // delay based on speed
#define SPEEDMIN 240 // minimum speed, nm/min: slower than 240 incompatible with current delay scheme
#define SPEEDMAX 420 // Speed max, nm/min, max=420 for stepInterval=4000
#define SPEEDINCR 60 // scan speeds multiple of 60 nm/min
//long autoscan_speed=0; //initialize autoscan speed 
#define COARSEBUTTONINCR 10 // multiplier for faster scrolling (manual) and setting auto endpoints

// Wavelength configuration and counters
#define STEPSOFFSET 8984   // Offset after homing
//long stepCounter = 0;            // Tracks current step position from home
#define STARTPOSITION 546  // Start position in nm (green mercury line)
//long position;                   // current position in nm
#define POSITIONMAX 1000  // longest wavelength allowed
#define POSITIONMIN 240   // shortest wavelength allowed
#define POSITIONINCR 1 // increment for position selection button presses 
// ******** END INSTRUMENT-SPECIFIC CALIBRATION ***************

#endif

#ifdef NIR

#define INSTRTYPE "NIR-local"

// Polynomial constants to convert nm position to steps, from calibration
#define C0  0
// currently only c1 is needed: negative since increasing steps leads to shorter wavelength position
#define C1  -8  // NIR: 8 steps per nm. 80 steps per second, below. So 10 nm/s scanning
#define C2  0
#define C3  0

// speed selection
// stepInterval in us: ex: 1000000 / (2*nm_per_min*8/60) with c1=(-)8
#define STEPINTERVAL 6250;  // 80 steps per second
//long speed_nm_min=0; // selected speed in nm/min
//long slow_us=0;   // delay based on speed
#define SPEEDMIN 300 // minimum speed, nm/min: slower than 300 incompatible with current delay scheme
#define SPEEDMAX 600 // Speed max, nm/min, max=600 for stepInterval=6250
#define SPEEDINCR 60 // scan speeds multiple of 60 nm/min
//long autoscan_speed=0; //initialize autoscan speed 
#define COARSEBUTTONINCR 1 // multiplier for faster scrolling (manual) and setting auto endpoints

// Wavelength configuration and counters
#define STEPSOFFSET 1440   // Offset after homing
//long stepCounter = 0;            // Tracks current step position from home
#define STARTPOSITION 1990  // Start position in nm
//long position;                   // current position in nm
#define POSITIONMAX 2000  // longest wavelength allowed
#define POSITIONMIN 700   // shortest wavelength allowed
#define POSITIONINCR 10 // increment for position selection button presses 
// ******** END INSTRUMENT-SPECIFIC CALIBRATION ***************

#endif

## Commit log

2026-08-09 setup og variation and edit README.md, LICENSE
    [LCD mini breadboard soldered.fzz, arduino basic lab instrument.fzz, greytak basic lab instrument idea.brd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]
2026-09-29 Create bipolar stepper motor shield parts and notes.pptx
2026-09-29 Update bipolar stepper motor shield parts and notes.pptx
    Add external wiring description
2026-10-02 created arduino-mono-vis program
    This is a copy of arduino-mono-nir, but has visible calibration values and steps-to-nm (16 steps per nm) conversion.
    Also added button_speed feature from arduino-bli demo repo, allowing long button presses to accelerate selection of the manual wavelength. button_speed is permanently enabled for selecting auto-scan 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
    Current version of program has a value for autoscan_Cycles but it is permanently set to 1 and the ability to select it is not yet added to the auto part of the program.
    [motor_calibration.xlsx]
2026-10-02 Update arduino-mono-vis.ino
    update splash message to monoVIS
2026-10-05 increased scan range
    [motor_calibration.xlsx]
2026-10-05 updated comments and motor calibration notes
    [motor_calibration.xlsx]
2026-10-09 Update arduino-mono-vis.ino
    A number of updates for visible controller performance, code cleanup, and prep for a common code base with NIR
2026-10-09 some bug fixes and adjust NIR calibration
    [settings.h]
2026-10-09 rename arduino-mono-vis to arduino-mono-local
    settings for each instrument in settings.h
2026-10-10 Updated comments in arduino-mono-local
